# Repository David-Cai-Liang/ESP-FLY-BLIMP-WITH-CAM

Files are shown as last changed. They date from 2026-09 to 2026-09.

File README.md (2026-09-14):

# ESP-FLY Blimp

A vision-tracking, IMU-stabilized blimp controlled wirelessly from a keyboard, built on two ESP32 boards linked over **ESP-NOW** and bridged to a PC over **USB serial**.

```
 ┌──────────────┐   USB Serial    ┌────────────────┐   ESP-NOW (2.4GHz)   ┌──────────────┐
 │ base_station │ <────wired────> │  Base Station  │ <──────wireless─────>│    Blimp     │
 │     .py      │  (keyboard in,  │    (ESP32)     │   telemetry / ctrl   │   (ESP32)    │
 │   (your PC)  │  telemetry out) │base_station.ino│                      │  blimp.ino   │
 └──────────────┘                 └────────────────┘                      └──────┬───────┘
                                                                                 │
                                                    ┌────────────────┬───────────┴──────────┬─────────────────────┐
                                                    │                │                      │                     │
                                                Vision (cam)      IMU (MPU6050)         State Machine          4x Motors
                                                Vision.cpp/h      IMU.cpp/h           StateMachine.cpp/h      (analogWrite)
```

## How it works

1. **Blimp** runs an onboard camera + IMU + state machine + battery-voltage loop, packages the readings into a `TelemetryPacket`, and transmits it to the base station over ESP-NOW every loop iteration. It listens for `ControlPacket`s from the base station (carrying motor inputs and active control mode) and drives 4 motors via `analogWrite`.
2. **Base station (ESP32)** acts as a relay: it forwards every `TelemetryPacket` from the blimp to USB serial (framed with headers/footers), and forwards any `ControlPacket` read from serial over ESP-NOW to the blimp.
3. **base_station.py** runs on your PC, reads user control input, computes motor values at ~20 Hz, and writes them along with the control mode (`MANUAL` vs `AUTONOMOUS`) to the base station. Pressing `M` toggles control mode live. The script parses incoming telemetry, monitors frame timing, and displays live status and latency in the terminal.

## Repository contents

| File | Runs on | Purpose |
|---|---|---|
| `blimp.ino` | Blimp ESP32 | Main control loop, sensor sampling, ESP-NOW telemetry/control, and motor PWM updates |
| `StateMachine.h` / `StateMachine.cpp` | Blimp ESP32 | Autonomous state machine managing target tracking (yaw & pitch), waypoint turning, and searching |
| `Vision.h` / `Vision.cpp` | Blimp ESP32 | OV-series camera capture, Lab-color thresholding, blob tracking, pixel area accumulation, ROI locking |
| `IMU.h` / `IMU.cpp` | Blimp ESP32 | MPU6050 accelerometer/gyro readout |
| `Motor.h` / `Motor.cpp` | Blimp ESP32 | Defines `MotorData` outputs (M1–M4) and helper functions shared with telemetry |
| `BatteryMonitor.h` / `BatteryMonitor.cpp` | Blimp ESP32 | Reads battery voltage via resistive divider, samples ADC, and reports reconstructed pack voltage |
| `base_station.ino` | Base station ESP32 | Serial ⇄ ESP-NOW protocol bridge |
| `base_station.py` | PC | Keyboard/Xbox controller input, serial framing, live telemetry/latency dashboard |
| `calibrate.ino` | Blimp ESP32 | Standalone camera streamer — outputs JPEG frames over serial |
| `calibrate.py` | PC | Live LAB color-mask tuner for dialing in `THRESHOLD_BLIMP` |

## Hardware

**Blimp ESP32 (ESP-FLY board)**

| Motor | Function | GPIO | Propeller |
|---|---|---|---|
| M1 | Front Left | 7 | CCW |
| M2 | Rear Left/Top | 4 | CCW |
| M3 | Rear Right/Bottom | 3 | CW |
| M4 | Front Right | 1 | CW |

- Camera: OV-series module wired per `Vision.h` pin map (XCLK=10, PCLK=13, VSYNC=38, HREF=47, SIOD=40, SIOC=39, D0–D7 as defined), status LED on GPIO 21.
- IMU: MPU6050 on I²C, SDA=5, SCL=6, address `0x68`.
- Battery voltage sensing: resistive divider from `Vbat` to GPIO 2. Polled every `BATTERY_READ_INTERVAL_MS` (500 ms) and attached to `TelemetryPacket` as `battVoltage`.
- Balloon: 24-36 inch 2-sheet Foil Balloon.
- Frame: PLA printed structure.
- Current CAD Model: https://cad.onshape.com/documents/6abb47ea8df48ed88ff41eff/w/e55858d9c5f248cb883d609c/e/1d23eafa7f8f630fb687ec6b

**Base station ESP32**
- ESP32-S3 board connected via USB serial to PC.
  - Other ESP32 boards could be made to work with minor modification to the code base.

## Wireless protocol (ESP-NOW)

Two fixed-size `packed` structs are exchanged over ESP-NOW:

```cpp
// Blimp -> Base station
typedef struct __attribute__((packed)) {
  VisionData vision; // cx, cy, w, h, pixels
  IMUData imu;       // ax, ay, az, tz (4x float)
  MotorData motors;  // actual M1-M4 outputs (4x int16_t)
  float yawError;    // degrees of yaw needed to center target (+ => right)
  float battVoltage; // battery voltage in volts
  uint8_t state;     // reported state (STATE_MANUAL, STATE_TRACKING, STATE_TURNING, STATE_SEARCHING)
} TelemetryPacket;

// Base station -> Blimp
typedef struct __attribute__((packed)) {
  int16_t motors[4]; // M1, M2, M3, M4 inputs
  uint8_t mode;      // MODE_MANUAL (0) or MODE_AUTONOMOUS (1)
} ControlPacket;
```

`vision.pixels` reports the exact number of threshold-matching pixels in the detected target blob. This count is used directly by the state machine to determine proximity to target objects.

## Serial protocol (base station ⇄ PC)

```
Telemetry (Base Station -> PC):
  [ 4B header: 00 AA 55 FF ] [ TelemetryPacket Payload ] [ 2B footer: EE FF ]

Control (PC -> Base Station):
  [ 4B header: 00 BB 66 FF ] [ ControlPacket Payload ]
```

## Control modes & State Machine

Control mode is selectable live via the `mode` byte inside `ControlPacket`. Pressing `M` in `base_station.py` flips modes at runtime:

- `MODE_MANUAL` (`0`): Motor outputs are driven by the base station commands with IMU gyro-Z yaw damping (`STRAIGHT_KD * iData.tz`) on M1 and M4. `YawError` is camera based.
- `MODE_AUTONOMOUS` (`1`): Handled by the standalone `StateMachine` class (`StateMachine.h` / `StateMachine.cpp`). Manual stick inputs are bypassed while the state machine calculates motor commands based on vision tracking data and IMU telemetry.

### Autonomous State Machine Sub-States

1. **`STATE_TRACKING`**: Active when a target blob is detected (`w > 0 && h > 0`) and total blob size has not reached the turn threshold (`pixels <= TURNING_AREA`). `YawError` is camera based.
   - **Yaw Controller**: Calculates horizontal error (`yawError`) in degrees. If `|yawError| > YAW_DEADZONE_HALF_DEG` (1°), proportional thrust correction (`YAW_GAIN_PER_DEG = 10`) is applied across forward motors M1 and M4, combined with gyro rate damping (`TURN_KD = 5`).
   - **Pitch Controller**: Calculates vertical error (`pitchError`) in degrees using vertical FOV parameters (`VERTICAL_FOV_DEG = 44.6`). If `|pitchError| > PITCH_DEADZONE_HALF_DEG` (1°), proportional thrust correction (`PITCH_GAIN_PER_DEG = 5`) adjusts vertical thrust across M2 and M3 relative to `DEFAULT_UPWARD_POWER`.
2. **`STATE_TURNING`**: Triggered when `vData.pixels > TURNING_AREA` (29,500 pixels), indicating the blimp is close enough to a waypoint target. The blimp halts tracking and executes a closed-loop rotation sequence defined in `WAYPOINT_LIST` using IMU gyro yaw integration before advancing to the next waypoint. `YawError` is IMU based.
3. **`STATE_SEARCHING`**: Active when no visual target is visible. Maintains default forward and upward baseline thrust levels while attempting to acquire a target.

## Setup & Calibration

### 1. Color Mask Calibration
1. Flash `calibrate.ino` onto the ESP32.
2. Run `python calibrate.py` on your PC.
3. Adjust LAB thresholds live using keyboard inputs (`1`–`6` / `Q`–`Y`).
4. Apply calibrated values to `THRESHOLD_BLIMP` in `Vision.h`.

### 2. Ground Control
```bash
pip install pyserial pygame
python base_station.py
```

### Key Controls
- **WASD / QE**: Manual flight movement.
- **M**: Toggle control mode (`MANUAL` ⇄ `AUTONOMOUS`).
- **Ctrl+C**: Stop and force safe zero-thrust shutdown.

## Safety & Failsafe

If no `ControlPacket` is received within `CONTROL_TIMEOUT_MS` (1000 ms), the control link is marked as stale. In both `MODE_MANUAL` and `MODE_AUTONOMOUS`, motor outputs are immediately forced to zero until communication is restored.

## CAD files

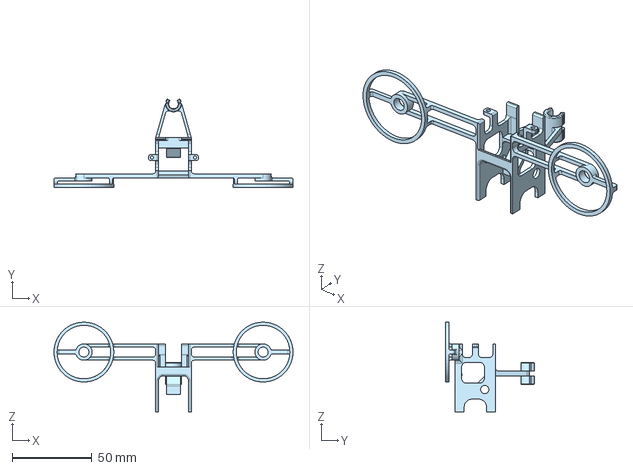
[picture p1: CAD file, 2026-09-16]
hardware/Board Housing.step
149.7 x 55.6 x 56.2 mm

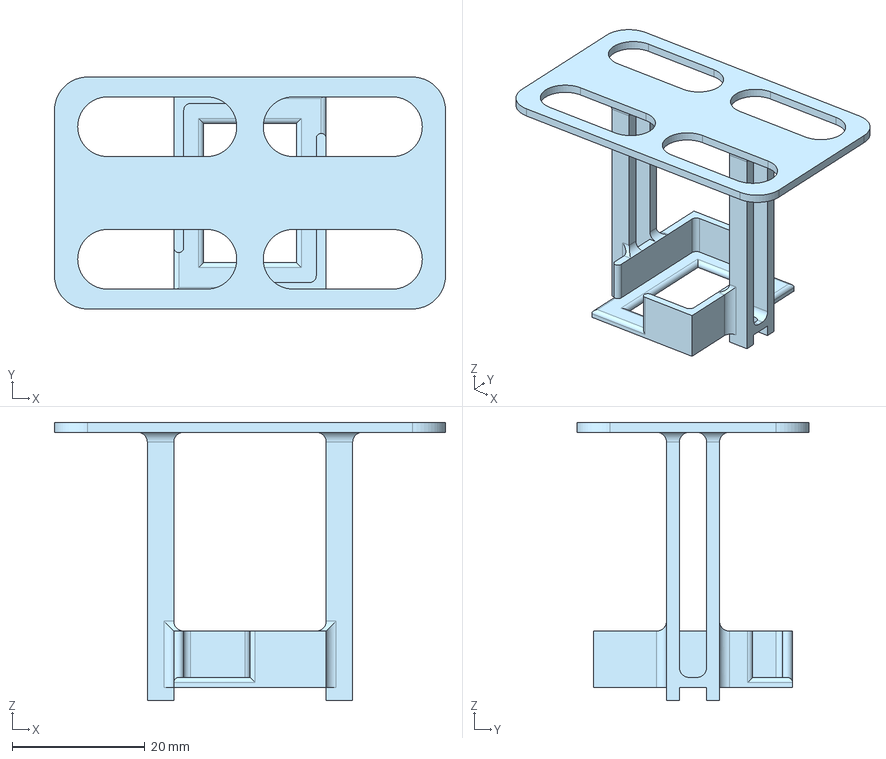
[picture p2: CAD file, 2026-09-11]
hardware/Small Battery Holder.step
59.0 x 35.0 x 42.0 mm

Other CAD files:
hardware/Board Housing.stl
hardware/Small Battery Holder.stl

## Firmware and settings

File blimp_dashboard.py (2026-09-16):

#!/usr/bin/env python3
"""
ESP-FLY Blimp Telemetry Dashboard
==================================

A pygame-based ground-control visualizer for the ESP-FLY autonomous blimp.

It can run in two modes:
  1. REPLAY  - parses a flight.log file produced by base_station.py and
               plays it back frame by frame (play/pause/scrub/speed).
  2. LIVE    - reads newline-framed telemetry from a serial port using the
               same text format base_station.py prints, OR tails a growing
               log file (e.g. `tail -f flight.log`) in real time.

Usage:
    python blimp_dashboard.py flight.log            # replay a log file
    python blimp_dashboard.py --live COM5           # live serial (pyserial)
    python blimp_dashboard.py --tail flight.log      # tail a live-growing log

Controls (replay mode):
    SPACE       play / pause
    LEFT/RIGHT  step one frame back / forward (while paused)
    UP/DOWN     increase / decrease playback speed
    R           restart from beginning
    click bar   scrub to a point in the log
    ESC / Q     quit

Only the Python standard library + pygame are required for log replay.
`pyserial` is only needed for --live serial mode.
"""

import sys
import re
import math
import argparse
import time
from collections import deque

import pygame

# --------------------------------------------------------------------------
# Parsing
# --------------------------------------------------------------------------

# Example telemetry line (see base_station.py output / README):
# [TELEMETRY] Motors: [0, 0, 0, 0] || Vision: CX:  0 CY:  0 W:  0 H:  0 Px:    0
#   || IMU: AX: -0.4 AY: -0.7 AZ: -8.8 TZ: -0.0 || Yaw Error:-28.7deg
#   || Batt: 3.58V  || State: MANUAL
TELEMETRY_RE = re.compile(
    r"\[TELEMETRY\]\s*Motors:\s*\[([-\d,\s]+)\]\s*\|\|\s*"
    r"Vision:\s*CX:\s*(-?\d+)\s*CY:\s*(-?\d+)\s*W:\s*(-?\d+)\s*H:\s*(-?\d+)\s*Px:\s*(-?\d+)\s*\|\|\s*"
    r"IMU:\s*AX:\s*(-?[\d.]+)\s*AY:\s*(-?[\d.]+)\s*AZ:\s*(-?[\d.]+)\s*TZ:\s*(-?[\d.]+)\s*\|\|\s*"
    r"Yaw Error:\s*(-?[\d.]+)deg\s*\|\|\s*"
    r"Batt:\s*([\d.]+)V\s*\|\|\s*"
    r"State:\s*(\w+)"
)

# [COMMAND] Mode: MANUAL                || Motors: [0, 20, 0, 0]
COMMAND_RE = re.compile(
    r"\[COMMAND\]\s*Mode:\s*(\w+)\s*\|\|\s*Motors:\s*\[([-\d,\s]+)\]"
)

# [LATENCY] Delta:   4.0ms | Avg:   4.6ms | Rate: 219.5 FPS | Queue: 0B
LATENCY_RE = re.compile(
    r"\[LATENCY\]\s*Delta:\s*([\d.]+)ms\s*\|\s*Avg:\s*([\d.]+)ms\s*\|\s*"
    r"Rate:\s*([\d.]+)\s*FPS\s*\|\s*Queue:\s*(\d+)B"
)

TIMESTAMP_RE = re.compile(r"\[(\d{4}-\d{2}-\d{2} \d{2}:\d{2}:\d{2}\.\d+)\]")


def _parse_motor_list(s):
    return [int(x.strip()) for x in s.split(",") if x.strip() != ""]


class Frame:
    """One fully-assembled telemetry/command/latency sample."""

    __slots__ = (
        "timestamp", "motors_actual", "cx", "cy", "w", "h", "pixels",
        "ax", "ay", "az", "tz", "yaw_error", "batt", "state",
        "cmd_mode", "cmd_motors",
        "lat_delta", "lat_avg", "rate_fps", "queue",
    )

    def __init__(self):
        self.timestamp = None
        self.motors_actual = [0, 0, 0, 0]
        self.cx = self.cy = self.w = self.h = self.pixels = 0
        self.ax = self.ay = self.az = self.tz = 0.0
        self.yaw_error = 0.0
        self.batt = 0.0
        self.state = "UNKNOWN"
        self.cmd_mode = "UNKNOWN"
        self.cmd_motors = [0, 0, 0, 0]
        self.lat_delta = self.lat_avg = self.rate_fps = 0.0
        self.queue = 0


def parse_log(path):
    """Parse a full flight.log file into a list of Frame objects."""
    frames = []
    current = None
    with open(path, "r", errors="replace") as f:
        for raw in f:
            line = raw.strip()
            if not line:
                continue

            ts_match = TIMESTAMP_RE.fullmatch(line)
            if ts_match:
                if current is not None:
                    frames.append(current)
                current = Frame()
                current.timestamp = ts_match.group(1)
                continue

            if current is None:
                continue

            m = TELEMETRY_RE.search(line)
            if m:
                current.motors_actual = _parse_motor_list(m.group(1))
                current.cx = int(m.group(2))
                current.cy = int(m.group(3))
                current.w = int(m.group(4))
                current.h = int(m.group(5))
                current.pixels = int(m.group(6))
                current.ax = float(m.group(7))
                current.ay = float(m.group(8))
                current.az = float(m.group(9))
                current.tz = float(m.group(10))
                current.yaw_error = float(m.group(11))
                current.batt = float(m.group(12))
                current.state = m.group(13)
                continue

            m = COMMAND_RE.search(line)
            if m:
                current.cmd_mode = m.group(1)
                current.cmd_motors = _parse_motor_list(m.group(2))
                continue

            m = LATENCY_RE.search(line)
            if m:
                current.lat_delta = float(m.group(1))
                current.lat_avg = float(m.group(2))
                current.rate_fps = float(m.group(3))
                current.queue = int(m.group(4))
                continue

    if current is not None:
        frames.append(current)
    # drop frames that never got a TELEMETRY line (incomplete/trailing)
    return [fr for fr in frames if fr.state != "UNKNOWN" or fr.timestamp is not None]


class LiveLineAssembler:
    """Feed it raw lines one at a time (from a socket/serial/tail) and it
    yields completed Frame objects, same schema as parse_log()."""

    def __init__(self):
        self.current = None

    def feed_line(self, line):
        line = line.strip()
        if not line:
            return None
        ts_match = TIMESTAMP_RE.fullmatch(line)
        if ts_match:
            done = self.current
            self.current = Frame()
            self.current.timestamp = ts_match.group(1)
            return done

        if self.current is None:
            return None

        m = TELEMETRY_RE.search(line)
        if m:
            c = self.current
            c.motors_actual = _parse_motor_list(m.group(1))
            c.cx, c.cy, c.w, c.h, c.pixels = (int(m.group(i)) for i in (2, 3, 4, 5, 6))
            c.ax, c.ay, c.az, c.tz = (float(m.group(i)) for i in (7, 8, 9, 10))
            c.yaw_error = float(m.group(11))
            c.batt = float(m.group(12))
            c.state = m.group(13)
            return None

        m = COMMAND_RE.search(line)
        if m:
            self.current.cmd_mode = m.group(1)
            self.current.cmd_motors = _parse_motor_list(m.group(2))
            return None

        m = LATENCY_RE.search(line)
        if m:
            c = self.current
            c.lat_delta, c.lat_avg, c.rate_fps = (float(m.group(i)) for i in (1, 2, 3))
            c.queue = int(m.group(4))
            return None
        return None


# --------------------------------------------------------------------------
# Visual theme
# --------------------------------------------------------------------------

BG = (14, 17, 22)
PANEL_BG = (22, 26, 33)
PANEL_BORDER = (45, 52, 63)
TEXT = (222, 227, 233)
TEXT_DIM = (128, 138, 150)
ACCENT = (86, 182, 255)
GREEN = (94, 214, 130)
YELLOW = (230, 196, 70)
RED = (230, 90, 90)
ORANGE = (235, 150, 70)
MOTOR_COLOR = (86, 182, 255)
GRID_COLOR = (35, 40, 49)

STATE_COLORS = {
    "MANUAL": ACCENT,
    "STATE_TRACKING": GREEN,
    "TRACKING": GREEN,
    "STATE_TURNING": ORANGE,
    "TURNING": ORANGE,
    "STATE_SEARCHING": YELLOW,
    "SEARCHING": YELLOW,
}


def lerp_color(c1, c2, t):
    t = max(0.0, min(1.0, t))
    return tuple(int(c1[i] + (c2[i] - c1[i]) * t) for i in range(3))


def batt_color(v):
    # rough single-cell LiPo curve: 4.2 full, 3.5 nominal-low, 3.2 critical
    if v >= 3.9:
        return GREEN
    if v >= 3.5:
        return lerp_color(YELLOW, GREEN, (v - 3.5) / 0.4)
    return lerp_color(RED, YELLOW, max(0.0, (v - 3.2) / 0.3))


# --------------------------------------------------------------------------
# Drawing helpers
# --------------------------------------------------------------------------

def panel(surface, rect, title, font_title):
    pygame.draw.rect(surface, PANEL_BG, rect, border_radius=8)
    pygame.draw.rect(surface, PANEL_BORDER, rect, width=1, border_radius=8)
    if title:
        label = font_title.render(title, True, TEXT_DIM)
        surface.blit(label, (rect.x + 12, rect.y + 8))
    return pygame.Rect(rect.x + 12, rect.y + 30, rect.width - 24, rect.height - 42)


def draw_text(surface, text, pos, font, color=TEXT, align="left"):
    img = font.render(text, True, color)
    r = img.get_rect()
    if align == "left":
        r.topleft = pos
    elif align == "center":
        r.midtop = pos
    elif align == "right":
        r.topright = pos
    surface.blit(img, r)
    return r


class Sparkline:
    """Rolling strip-chart for a scalar over time."""

    def __init__(self, maxlen=240):
        self.data = deque(maxlen=maxlen)

    def push(self, v):
        self.data.append(v)

    def draw(self, surface, rect, color, font, label="", lo=None, hi=None, unit=""):
        pygame.draw.rect(surface, (17, 20, 26), rect, border_radius=4)
        pygame.draw.rect(surface, GRID_COLOR, rect, width=1, border_radius=4)
        if len(self.data) < 2:
            return
        vals = list(self.data)
        vmin = lo if lo is not None else min(vals)
        vmax = hi if hi is not None else max(vals)
        if vmax - vmin < 1e-6:
            vmax = vmin + 1.0
        n = len(vals)
        # inset the plot area by 1px so the line's stroke width never draws
        # over the box's own border, then clip to it as a hard guarantee
        plot_rect = rect.inflate(-2, -2)
        pts = []
        for i, v in enumerate(vals):
            x = plot_rect.x + i / (n - 1) * plot_rect.width
            t = (v - vmin) / (vmax - vmin)
            t = max(0.0, min(1.0, t))
            y = plot_rect.bottom - t * plot_rect.height
            pts.append((x, y))
        prev_clip = surface.get_clip()
        surface.set_clip(plot_rect)
        if len(pts) >= 2:
            pygame.draw.lines(surface, color, False, pts, 2)
        surface.set_clip(prev_clip)
        cur = vals[-1]
        draw_text(surface, f"{label} {cur:.1f}{unit}", (rect.x + 6, rect.y + 4), font, TEXT_DIM)


# --------------------------------------------------------------------------
# Panels
# --------------------------------------------------------------------------

MOTOR_LAYOUT = {
    # index -> (label, grid position (col,row))  matches README GPIO table
    0: ("M1 FL", (0, 0), "CW"),
    1: ("M2 RT", (0, 1), "CW"),
    2: ("M3 RB", (1, 1), "CCW"),
    3: ("M4 FR", (1, 0), "CCW"),
}


def draw_motor_panel(surface, rect, frame, font, font_small):
    inner = rect
    cx, cy = inner.centerx, inner.centery
    size = min(inner.width, inner.height) * 0.42

    # blimp body outline (top-down view)
    body_w, body_h = size * 1.9, size * 1.15
    body_rect = pygame.Rect(0, 0, body_w, body_h)
    body_rect.center = (cx, cy)
    pygame.draw.ellipse(surface, (40, 46, 56), body_rect)
    pygame.draw.ellipse(surface, PANEL_BORDER, body_rect, width=2)
    # nose direction arrow (forward = up)
    pygame.draw.polygon(
        surface, TEXT_DIM,
        [(cx, cy - body_h / 2 - 14), (cx - 8, cy - body_h / 2 + 2), (cx + 8, cy - body_h / 2 + 2)]
    )

    max_pwm = max(255, max(abs(m) for m in frame.motors_actual) if frame.motors_actual else 255)
    max_pwm = max(max_pwm, 60)

    for idx, (label, (col, row), spin) in MOTOR_LAYOUT.items():
        mx = cx + (col * 2 - 1) * size * 0.62
        my = cy + (row * 2 - 1) * size * 0.5
        val = frame.motors_actual[idx] if idx < len(frame.motors_actual) else 0
        cmd = frame.cmd_motors[idx] if idx < len(frame.cmd_motors) else 0
        t = min(1.0, abs(val) / max_pwm)
        radius = 16 + t * 22
        color = MOTOR_COLOR if val >= 0 else RED
        pygame.draw.circle(surface, (0, 0, 0, 0), (int(mx), int(my)), int(radius) + 4)
        pygame.draw.circle(surface, color, (int(mx), int(my)), int(radius), width=0)
        pygame.draw.circle(surface, TEXT, (int(mx), int(my)), int(radius), width=2)
        # spin direction indicator
        spin_txt = font_small.render(spin, True, (10, 12, 16))
        surface.blit(spin_txt, spin_txt.get_rect(center=(mx, my)))
        draw_text(surface, label, (mx, my + radius + 6), font_small, TEXT_DIM, align="center")
        draw_text(surface, f"act {val}", (mx, my + radius + 20), font_small, TEXT, align="center")
        draw_text(surface, f"cmd {cmd}", (mx, my + radius + 34), font_small, TEXT_DIM, align="center")


def draw_imu_panel(surface, rect, frame, font, font_small):
    cx, cy = rect.centerx, rect.centery - 6
    radius = min(rect.width, rect.height) * 0.36

    # roll/pitch style horizon using AX (roll-ish) / AY (pitch-ish)
    roll = math.atan2(frame.ax, 9.8) if abs(frame.ax) < 20 else 0
    pitch = math.atan2(frame.ay, 9.8) if abs(frame.ay) < 20 else 0

    pygame.draw.circle(surface, (17, 20, 26), (cx, cy), radius)
    clip_rect = pygame.Rect(cx - radius, cy - radius, radius * 2, radius * 2)
    prev_clip = surface.get_clip()
    surface.set_clip(clip_rect)

    horizon_y = cy + pitch * radius * 1.4
    sky_poly = [(cx - radius * 2, horizon_y - radius * 3)]
    ground_poly_h = radius * 3

    surf_size = int(radius * 2.2)
    tmp = pygame.Surface((surf_size * 2, surf_size * 2), pygame.SRCALPHA)
    tsky = (52, 92, 140)
    tground = (76, 58, 40)
    tmp.fill(tsky)
    pygame.draw.rect(tmp, tground, (0, surf_size, surf_size * 2, surf_size))
    rotated = pygame.transform.rotate(tmp, -math.degrees(roll))
    rrect = rotated.get_rect(center=(cx, horizon_y))
    surface.blit(rotated, rrect)

    surface.set_clip(prev_clip)
    pygame.draw.circle(surface, PANEL_BORDER, (cx, cy), radius, width=2)
    pygame.draw.line(surface, TEXT, (cx - 18, cy), (cx + 18, cy), 2)
    pygame.draw.line(surface, TEXT, (cx, cy - 6), (cx, cy + 6), 2)

    # yaw torque (tz, rad) as a small needle dial below
    dial_cy = cy + radius + 34
    dial_r = 22
    pygame.draw.circle(surface, (17, 20, 26), (cx, dial_cy), dial_r)
    pygame.draw.circle(surface, PANEL_BORDER, (cx, dial_cy), dial_r, width=1)
    tz_clamped = max(-math.pi, min(math.pi, frame.tz))
    ang = tz_clamped - math.pi / 2
    nx = cx + math.cos(ang) * dial_r * 0.85
    ny = dial_cy + math.sin(ang) * dial_r * 0.85
    pygame.draw.line(surface, YELLOW, (cx, dial_cy), (nx, ny), 3)
    draw_text(surface, "yaw torque", (cx, dial_cy + dial_r + 4), font_small, TEXT_DIM, align="center")

    draw_text(surface, f"AX {frame.ax:+.1f}", (rect.x, rect.bottom - 44), font_small, TEXT)
    draw_text(surface, f"AY {frame.ay:+.1f}", (rect.x, rect.bottom - 30), font_small, TEXT)
    draw_text(surface, f"AZ {frame.az:+.1f}", (rect.x, rect.bottom - 16), font_small, TEXT)
    draw_text(surface, f"TZ {frame.tz:+.2f} rad", (rect.right, rect.bottom - 16), font_small, TEXT, align="right")


CAM_W, CAM_H = 320, 240  # assumed sensor working resolution for scaling the blob box


def draw_vision_panel(surface, rect, frame, font, font_small):
    pygame.draw.rect(surface, (10, 12, 16), rect)
    pygame.draw.rect(surface, PANEL_BORDER, rect, width=1)

    sx = rect.width / CAM_W
    sy = rect.height / CAM_H
    scale = min(sx, sy)
    ox = rect.x + (rect.width - CAM_W * scale) / 2
    oy = rect.y + (rect.height - CAM_H * scale) / 2

    # crosshair + deadzone (2 deg yaw / pitch deadzone visualized as a center box)
    ccx, ccy = ox + CAM_W / 2 * scale, oy + CAM_H / 2 * scale
    pygame.draw.line(surface, GRID_COLOR, (ccx, oy), (ccx, oy + CAM_H * scale), 1)
    pygame.draw.line(surface, GRID_COLOR, (ox, ccy), (ox + CAM_W * scale, ccy), 1)
    # StateMachine.h: YAW/PITCH_DEADZONE_HALF_DEG = 1deg each way (tiny; drawn
    # at a small fixed size since exact deg->pixel mapping needs horizontal FOV,
    # which isn't published alongside VERTICAL_FOV_DEG in the README)
    dz_w, dz_h = 0.04 * CAM_W * scale, 0.04 * CAM_H * scale
    pygame.draw.rect(surface, (60, 66, 40), (ccx - dz_w / 2, ccy - dz_h / 2, dz_w, dz_h), width=1)

    has_target = frame.w > 0 and frame.h > 0
    if has_target:
        bx = ox + max(0, frame.cx - frame.w / 2) * scale
        by = oy + max(0, frame.cy - frame.h / 2) * scale
        bw = frame.w * scale
        bh = frame.h * scale
        box_color = GREEN if frame.state.upper() in ("STATE_TRACKING", "TRACKING") else ORANGE
        pygame.draw.rect(surface, box_color, (bx, by, bw, bh), width=2)
        blob_cx = ox + frame.cx * scale
        blob_cy = oy + frame.cy * scale
        pygame.draw.circle(surface, box_color, (int(blob_cx), int(blob_cy)), 3)
        # line from center to blob showing yaw error direction
        pygame.draw.line(surface, box_color, (ccx, ccy), (blob_cx, blob_cy), 1)
    else:
        draw_text(surface, "NO TARGET", (rect.centerx, rect.centery - 8), font, TEXT_DIM, align="center")

    draw_text(surface, f"cx {frame.cx} cy {frame.cy}", (rect.x + 6, rect.bottom - 46), font_small, TEXT)
    draw_text(surface, f"w {frame.w} h {frame.h}", (rect.x + 6, rect.bottom - 32), font_small, TEXT)
    draw_text(surface, f"pixels {frame.pixels}", (rect.x + 6, rect.bottom - 18), font_small, TEXT)

    # pixel-area bar vs TURNING_AREA threshold (StateMachineConfig::TURNING_AREA = 29500)
    bar_x, bar_y, bar_w, bar_h = rect.right - 130, rect.bottom - 26, 118, 14
    turning_area = 29500
    frac = min(1.0, frame.pixels / turning_area)
    pygame.draw.rect(surface, (30, 34, 41), (bar_x, bar_y, bar_w, bar_h), border_radius=3)
    fill_color = ORANGE if frac >= 1.0 else ACCENT
    pygame.draw.rect(surface, fill_color, (bar_x, bar_y, bar_w * frac, bar_h), border_radius=3)
    pygame.draw.rect(surface, PANEL_BORDER, (bar_x, bar_y, bar_w, bar_h), width=1, border_radius=3)
    draw_text(surface, "area / turn thresh", (bar_x, bar_y - 14), font_small, TEXT_DIM)


def draw_yaw_gauge(surface, rect, frame, font, font_small):
    cx = rect.centerx
    cy = rect.y + rect.height * 0.62
    radius = min(rect.width * 0.48, rect.height * 0.55)

    pygame.draw.arc(surface, GRID_COLOR, (cx - radius, cy - radius, radius * 2, radius * 2),
                     math.pi, 2 * math.pi, 3)
    for deg in range(-90, 91, 30):
        a = math.pi + math.radians(deg + 90)
        x1 = cx + math.cos(a) * radius
        y1 = cy + math.sin(a) * radius
        x2 = cx + math.cos(a) * (radius - 8)
        y2 = cy + math.sin(a) * (radius - 8)
        pygame.draw.line(surface, TEXT_DIM, (x1, y1), (x2, y2), 2)

    err = max(-90, min(90, frame.yaw_error))
    a = math.pi + math.radians(err + 90)
    nx = cx + math.cos(a) * (radius - 4)
    ny = cy + math.sin(a) * (radius - 4)
    color = GREEN if abs(err) <= 2 else (YELLOW if abs(err) <= 15 else RED)
    pygame.draw.line(surface, color, (cx, cy), (nx, ny), 3)
    pygame.draw.circle(surface, TEXT, (cx, cy), 4)

    draw_text(surface, f"Yaw Error {frame.yaw_error:+.1f}\u00b0", (cx, cy - radius - 18), font, color, align="center")
    draw_text(surface, "L", (cx - radius - 4, cy - 6), font_small, TEXT_DIM, align="right")
    draw_text(surface, "R", (cx + radius + 4, cy - 6), font_small, TEXT_DIM)


def draw_state_panel(surface, rect, frame, font, font_small):
    states = ["MANUAL", "STATE_SEARCHING", "STATE_TRACKING", "STATE_TURNING"]
    display = {
        "MANUAL": "MANUAL",
        "STATE_SEARCHING": "SEARCHING",
        "STATE_TRACKING": "TRACKING",
        "STATE_TURNING": "TURNING",
    }
    cur = frame.state.upper()
    # normalize possible short forms
    alias = {"SEARCHING": "STATE_SEARCHING", "TRACKING": "STATE_TRACKING", "TURNING": "STATE_TURNING"}
    cur = alias.get(cur, cur)

    n = len(states)
    box_w = rect.width / n - 8
    box_h = min(rect.height * 0.78, rect.height - 26)
    y = rect.y + 4
    for i, s in enumerate(states):
        x = rect.x + i * (box_w + 8)
        active = (s == cur)
        color = STATE_COLORS.get(s, ACCENT) if active else (30, 34, 41)
        border = STATE_COLORS.get(s, ACCENT)
        r = pygame.Rect(x, y, box_w, box_h)
        pygame.draw.rect(surface, color, r, border_radius=6)
        pygame.draw.rect(surface, border, r, width=2, border_radius=6)
        txt_color = (10, 12, 16) if active else TEXT_DIM
        draw_text(surface, display[s], (r.centerx, r.y + 6), font_small, txt_color, align="center")

    mode_color = GREEN if frame.cmd_mode.upper() == "AUTONOMOUS" else ACCENT
    draw_text(surface, f"CMD MODE: {frame.cmd_mode}", (rect.x, y + box_h + 10), font, mode_color)


LOW_BATT_THRESHOLD = 3.3  # BatteryMonitor.h default setLowBatteryThreshold() (1S LiPo storage-safe level)
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

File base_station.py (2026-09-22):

import os
import struct
import sys
import threading
import time
import pygame
import serial

# Enable VT100 ANSI escape sequence support on Windows terminal
if sys.platform == "win32":
    os.system("")

SERIAL_PORT = "/dev/cu.usbmodem101"  # Adjust for your OS ('/dev/ttyUSB0' or '/dev/ttyACM0')
BAUD_RATE = 115200

FLIGHT_LOG_PATH = "flight.log"  # wiped at the start of each run, then appended to

# Protocol Markers
TELEMETRY_HEADER = b"\x00\xAA\x55\xFF"
TELEMETRY_FOOTER = b"\xEE\xFF"
CONTROL_HEADER = b"\x00\xBB\x66\xFF"

PAYLOAD_SIZE = 45  # Updated Payload Size: 4x uint16 (8B) + 1x uint32 (4B) + 4x float (16B) + 4x int16 (8B) + 2x float (8B) + 1x uint8 (1B)
TOTAL_FRAME_SIZE = 4 + PAYLOAD_SIZE + 2  # 47 Bytes Total Frame

# Autonomous sub-state, reported in telemetry.state (must match blimp.ino's
# STATE_MANUAL / STATE_TRACKING / STATE_TURNING / STATE_SEARCHING). Always
# STATE_MANUAL while the blimp itself is in MODE_MANUAL.
STATE_MANUAL = 0
STATE_TRACKING = 1
STATE_TURNING = 2
STATE_SEARCHING = 3
STATE_NAMES = {
    STATE_MANUAL: "MANUAL",
    STATE_TRACKING: "TRACKING",
    STATE_TURNING: "TURNING",
    STATE_SEARCHING: "SEARCHING",
}

# Yaw-to-target is now computed on the blimp (see blimp.ino: HORIZONTAL_FOV_DEG /
# DEG_PER_PIXEL / yawError) and arrives as part of the telemetry payload below.

# Must match BatteryMonitor.h's default low-battery threshold on the blimp,
# used here only to color/flag the status display -- the blimp itself is the
# authority on when the battery is actually low (its LED, if wired, reflects that).
LOW_BATTERY_THRESHOLD_V = 3.3

# Control modes (must match blimp.ino's MODE_MANUAL / MODE_PROPORTIONAL)
MODE_MANUAL = 0
MODE_PROPORTIONAL = 1
MODE_NAMES = {MODE_MANUAL: "MANUAL", MODE_PROPORTIONAL: "AUTONOMOUS (yaw-only)"}

# Xbox controller tuning
CONTROLLER_MAX_POWER = 200      # absolute cap on any motor value from the controller
CONTROLLER_DEADZONE = 0.15      # ignore stick noise near center
DEFAULT_UPWARD_POWER = 20             # matches the keyboard path's idle m2 value

# Axis indices are for the common SDL2/XInput mapping (Xbox 360 / Xbox One
# controllers on Windows & most Linux setups via pygame 2.x). If your sticks
# don't move the right motors, run `python base_station.py --calibrate`
# to print live axis values and adjust the indices below.
AXIS_LEFT_X = 0
AXIS_LEFT_Y = 1
AXIS_RIGHT_Y = 4
BUTTON_MODE_TOGGLE = 0  # "A" button

# Maps pygame key constants to the same single-char tokens the rest of the
# code (compute_motors, MODE toggle, etc.) already expects.
KEY_MAP = {
    pygame.K_w: "w",
    pygame.K_a: "a",
    pygame.K_d: "d",
    pygame.K_q: "q",
    pygame.K_e: "e",
    pygame.K_m: "m",
}

# Keyboard state management
active_keys = set()
current_mode = MODE_MANUAL  # start safe: manual control until the pilot opts in

# Controller state
joystick = None
controller_button_prev = set()

# Display state
screen = None
status_font = None
STATUS_BG = (15, 15, 15)
STATUS_FG = (0, 230, 110)

# --- Telemetry reader thread state -----------------------------------------
# Telemetry is parsed on a dedicated background thread so that a burst of
# buffered serial data (e.g. a backlog of frames, or debug text the firmware
# writes straight onto the same serial line) can never block the main loop's
# keyboard/controller polling or 20 Hz control-command transmission. The two
# threads only share `latest_telemetry`, guarded by `telemetry_lock`.
telemetry_lock = threading.Lock()
latest_telemetry = {
    "actual_motors": [0, 0, 0, 0],
    "cx": 0, "cy": 0, "w": 0, "h": 0, "pixels": 0,
    "ax": 0.0, "ay": 0.0, "az": 0.0, "tz": 0.0,
    "yaw_err": 0.0,
    "batt_voltage": 0.0,
    "state": STATE_MANUAL,
    "delta_ms": 0.0,
    "avg_dt": 0.0,
    "fps": 0.0,
    "total_frames": 0,
    "queue_bytes": 0,
    "frame_deltas": [],
}
stop_event = threading.Event()


def init_keyboard_window():
    """
    pygame.key needs a display surface with window focus to receive keyboard
    events, so we open a small control window. Click into it to give it focus.
    This same window also mirrors whatever gets printed to the terminal.
    """
    global screen, status_font
    screen = pygame.display.set_mode((1500, 100))
    pygame.display.set_caption("Base Station Controls (click here for keyboard focus)")
    pygame.key.set_repeat(0)  # disabled: we want press edges, not OS key-repeat
    status_font = pygame.font.SysFont("consolas,couriernew,monospace", 16)
    return screen


def render_status(lines):
    """Draw the same status lines shown in the terminal onto the pygame window."""
    if screen is None:
        return
    screen.fill(STATUS_BG)
    y = 8
    for line in lines:
        surf = status_font.render(line, True, STATUS_FG)
        screen.blit(surf, (10, y))
        y += surf.get_height() + 4
    pygame.display.flip()


def process_keyboard_events():
    """
    Poll pygame's event queue and update active_keys / current_mode.
    Returns False if the window was closed (used as a shutdown signal).
    """
    global current_mode

    for event in pygame.event.get():
        if event.type == pygame.QUIT:
            return False

        elif event.type == pygame.KEYDOWN:
            c = KEY_MAP.get(event.key)
            if c is not None:
                # KEYDOWN only fires once per physical press (repeat is
                # disabled above), so this is naturally the press edge.
                if c == "m":
                    current_mode = MODE_PROPORTIONAL if current_mode == MODE_MANUAL else MODE_MANUAL
                active_keys.add(c)

        elif event.type == pygame.KEYUP:
            c = KEY_MAP.get(event.key)
            if c is not None:
                active_keys.discard(c)

    return True


def compute_motors():
    m1, m2, m3, m4 = 0, DEFAULT_UPWARD_POWER, 0, 0

    if "w" in active_keys:
        m1 += 50
        m4 += 50
    if "a" in active_keys:
        m4 += 50
    if "d" in active_keys:
        m1 += 50
    if "q" in active_keys:
        m3 += 50
    if "e" in active_keys:
        m2 += 50

    return [m1, m2, m3, m4]


def apply_deadzone(value, deadzone=CONTROLLER_DEADZONE):
    """Zero out stick noise near center and rescale the remaining range to 0-1."""
    if abs(value) < deadzone:
        return 0.0
    sign = 1.0 if value > 0 else -1.0
    return sign * (abs(value) - deadzone) / (1.0 - deadzone)


def init_controller():
    """Attempt to detect and open an Xbox (or compatible) controller. Returns None if unavailable."""
    pygame.joystick.init()

    if pygame.joystick.get_count() == 0:
        print("No controller detected — falling back to keyboard-only control.")
        return None

    js = pygame.joystick.Joystick(0)
    js.init()
    print(f"Controller connected: {js.get_name()}")
    return js
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

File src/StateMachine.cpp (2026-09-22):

#include "StateMachine.h"

using namespace StateMachineConfig;

// Wraps an angle in radians to the range [-PI, PI).
static float wrapPI(float angleRad) {
  while (angleRad >= PI) angleRad -= 2 * PI;
  while (angleRad < -PI) angleRad += 2 * PI;
  return angleRad;
}

// Applies `correction` to `primary`. If that would push `primary` past
// TURN_MAX_POWER (mirrors MOTOR_MAX in blimp.ino), `primary` is clamped and
// the leftover ("overflow") correction is bled into `secondary` (decreasing
// it) instead of being discarded. This keeps the differential response
// roughly linear over a wider range before it fully saturates, rather than
// flattening out the instant one motor hits its cap.
//
// Takes/returns plain values (not references) because MotorData's fields
// live in a packed struct — you can't bind a non-const reference directly
// to a packed field.
struct DifferentialCorrection {
  int primary;
  int secondary;
};

static DifferentialCorrection applyDifferentialCorrection(int primary, int secondary, int correction) {
 primary += correction;
 if (primary > TURN_MAX_POWER) {
   int overflow = primary - (int)TURN_MAX_POWER;
   primary = (int)TURN_MAX_POWER;
   secondary -= overflow;
 }
 return {primary, secondary};
}


MotorData StateMachine::update(const VisionData &vData, const YawState &yaw, float yawError, float pitchError) {
  MotorData out;
  out.m1 = out.m4 = DEFAULT_FORWARD_POWER;
  state_ = STATE_SEARCHING;

  //Maintain Altitude
  out.m2 = max(0, currUpwardPower_);
  out.m3 = max(0, -currUpwardPower_);
  if (turnInProgress_) {
    state_ = STATE_TURNING;

    // Heading is integrated by the IMU sampler at IMU_SAMPLE_HZ, so progress
    // is just the delta since the turn was committed — no integration here,
    // and no dependence on however long the camera took this frame.
    turnedSoFar_ = yaw.yawRad - turnStartYawRad_;

    float turnYawError = wrapPI(WAYPOINT_LIST[waypointIndex_] - turnedSoFar_);
    int correction = (int)((fabs(turnYawError) - TURN_DEADBAND_RAD) * TURN_KP);

    if (turnYawError >= 0) {
      DifferentialCorrection r = applyDifferentialCorrection(out.m1, out.m4, correction);
      out.m1 = r.primary;
      out.m4 = r.secondary;
    } else {
      DifferentialCorrection r = applyDifferentialCorrection(out.m4, out.m1, correction);
      out.m4 = r.primary;
      out.m1 = r.secondary;
    }
    // Control Yaw Rate
    out.m1 -= TURN_KD * yaw.rateRad;
    out.m4 += TURN_KD * yaw.rateRad;

    if (fabs(turnYawError) <= TURN_DEADBAND_RAD && fabs(yaw.rateRad) <= TURN_RATE_SETTLE) {
      turnInProgress_ = false;
      waypointIndex_ = (waypointIndex_ + 1) % WAYPOINT_COUNT;
    }

  } else {
    bool targetVisible = (vData.w > 0 && vData.h > 0);
    bool closeEnough = (vData.w * vData.h > TURNING_AREA);

    // Require CLOSE_ENOUGH_FRAME_CONFIRM consecutive close-enough frames
    // before actually committing to a turn, so a single oversized/noisy
    // detection can't trigger one. Any frame that drops back below
    // TURNING_AREA resets the streak.
    closeEnoughFrameCount_ = closeEnough ? (closeEnoughFrameCount_ + 1) : 0;
    bool turnConfirmed = closeEnough && (closeEnoughFrameCount_ >= CLOSE_ENOUGH_FRAME_CONFIRM);

    if (!turnConfirmed && targetVisible) {
      state_ = STATE_TRACKING;
      wiggleSearchActive_ = false;

      // Yaw Control
      if (fabs(yawError) > YAW_DEADZONE_HALF_DEG) {
        int correction = (int)((fabs(yawError) - YAW_DEADZONE_HALF_DEG) * YAW_GAIN_PER_DEG);
        if (yawError > 0) {
          DifferentialCorrection r = applyDifferentialCorrection(out.m4, out.m1, correction);
          out.m4 = r.primary;
          out.m1 = r.secondary;
        } else {
          DifferentialCorrection r = applyDifferentialCorrection(out.m1, out.m4, correction);
          out.m1 = r.primary;
          out.m4 = r.secondary;
        }
      }

      // Gyro-rate correction always applied while tracking
      out.m1 -= STRAIGHT_KD * yaw.rateRad;
      out.m4 += STRAIGHT_KD * yaw.rateRad;


      // Pitch Control
      if (fabs(pitchError) > PITCH_DEADZONE_HALF_DEG) {
        int correction = (int)((fabs(pitchError) - PITCH_DEADZONE_HALF_DEG) * PITCH_GAIN_PER_DEG);
        currUpwardPower_ = DEFAULT_UPWARD_POWER + correction;
      }
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

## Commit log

2026-08-17 Upload calibration code
2026-08-17 add hardware stack
    [Battery Holder.step, Battery Holder.stl, Board Housing.step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]
2026-08-19 add ability to run without camera
    [Board Housing.step, Board Housing.stl]
2026-08-20 Add more further details on the materials using in the blimp
2026-08-20 update hardware
    [Battery Holder.step, Battery Holder.stl, Board Housing.step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]
2026-08-21 Switch from pixel delta to reference yaw
    remove IMU-waypoint and wiggle search for simplicity
    Will add IMU-waypoint and wiggle search if they are necessary in the future
2026-08-21 fix battery holder screw slot
    [Battery Holder.step, Battery Holder.stl]
2026-08-22 Hardware + Software Update
    Add simple yaw controller to manual mode
    Reinforce controller support (Can now use controller to go up/down)
    Update hardware to minimize prop collisions and stuck PCBs
    [Battery Holder.step, Battery Holder.stl, Board Housing.step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]
2026-08-22 prepare to merge referenceYaw back into Main; add wiggle search and IMU-only control to referenceYaw
2026-08-23 increase YAW_GAIN_PER_DEG, switch from maximum speed guarantee to minimum speed guarantee
2026-08-24 prepare to add battery sensor via voltage divider
2026-08-24 implement battery sensor
2026-08-25 update battery divider pin to 2
2026-08-27 new hardware?
    [Board Housing.step]
2026-08-29 switched to non-blocking state machine
2026-09-03 WIP: sometimes turns correctly after approaching balloon
    [blimp.ino]
2026-09-05 add pitch control
    updated blimp.ino to support StateMachine.cpp
2026-09-05 Switch MOSFET speed from 5KHz to 25KHz
2026-09-05 update base station with number of pixels + error is IMU-based error only in STATE_TURNING otherwise it is camera-based
    [StateMachine.cpp, StateMachine.h, base_station.ino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]
2026-09-06 fix: packing issue issue removed
    [StateMachine.cpp]
2026-09-08 WIP: optimize camera-pitch PID, camera area threshold, imu-yaw PID
2026-09-08 switch back from masked pixel count to bounding box size
2026-09-09 update board housing
    [Board Housing.step, Board Housing.stl]
2026-09-10 slow down forward speed; add debouncing to camera area threshold
2026-09-11 hardware: make board housing lighter while reinforcing prop guard
    [Board Housing.step, Board Housing.stl]
2026-09-11 hardware: thicker side walls
    [Board Housing.step, Board Housing.stl, Small Battery Holder.step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]
2026-09-12 hardware: thicken prop guard
    [Board Housing.3mf, Board Housing.step, Board Housing.stl]
2026-09-12 remove junk file
    [Board Housing.3mf]
2026-09-12 hardware: lighten prop guard
    [Board Housing.step, Board Housing.stl]
2026-09-12 hardware: make the rear prop arm thinner
    [Board Housing.step, Board Housing.stl]
2026-09-14 add blimp_dashboard.py
    [Board Housing.3mf]
2026-09-14 remove .3mf file
    [Board Housing.3mf]
2026-09-14 increase yaw torque by ~25% by increasing radius
    [Board Housing.step, Board Housing.stl]
2026-09-15 increase yaw torque slightly
    [Board Housing.step, Board Housing.stl]
2026-09-15 wip: decrease spar length by 10mm; improve text in the GUI
    [Board Housing.step, Board Housing.stl]
2026-09-16 hardware: update snap connector
    [Board Housing.step, Board Housing.stl]
2026-09-19 use the last upward thrust value from straight when turning
    add a more advanced height controller if not enough
2026-09-22 calibrate gyro bias and move yaw integration ==> og was by vision pipline, MPU6050 sits at 1-3 deg/s of offset so 90 deg turn accumulates ~10 deg of error before jittery dt. NOW we measure gyro-Z bia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
    [IMU.cpp, IMU.h, StateMachine.cpp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]
